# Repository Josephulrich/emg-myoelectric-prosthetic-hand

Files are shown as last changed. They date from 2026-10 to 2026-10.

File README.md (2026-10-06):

<div align="center">

# EMG Myoelectric Prosthetic Hand

### 3D-printed robotic hand driven by muscle signals, with haptic, visual and audio feedback







**From muscle contraction to finger motion: a final-year biomedical instrumentation project at Sup Galilée, Sorbonne Paris Nord (2026).**

</div>

| Assembled prototype | On the test bench | Hands-on demo |
|---|---|---|
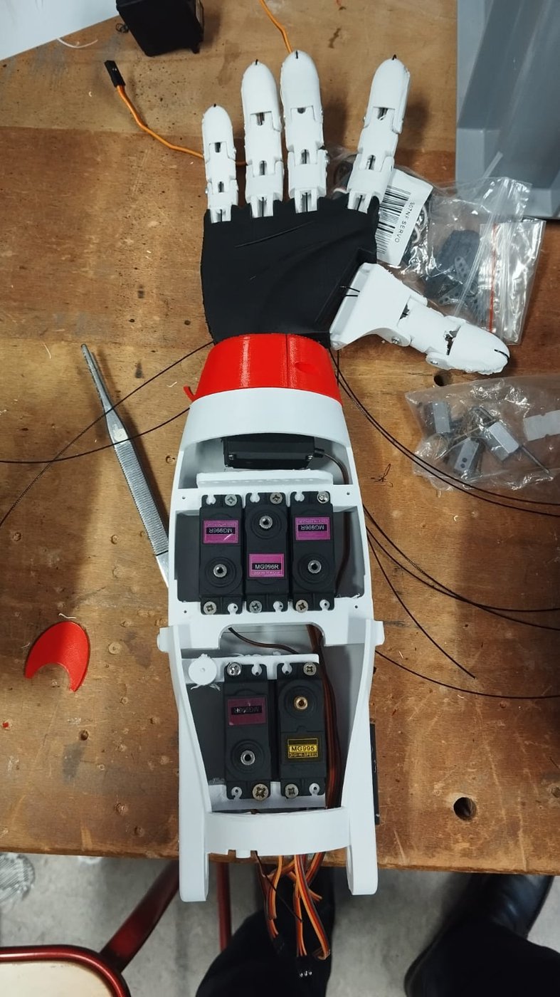
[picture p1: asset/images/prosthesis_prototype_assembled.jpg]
Prototype
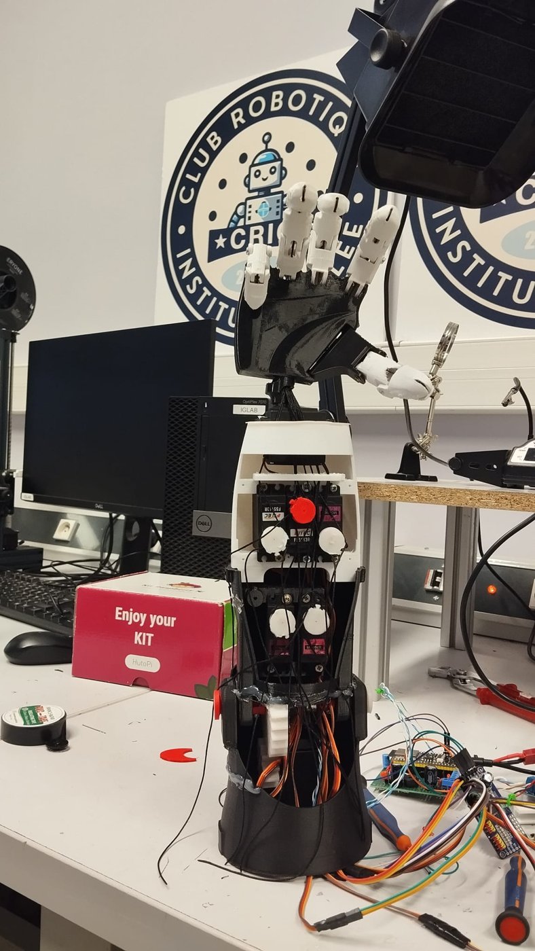
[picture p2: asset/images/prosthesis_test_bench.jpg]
Test bench
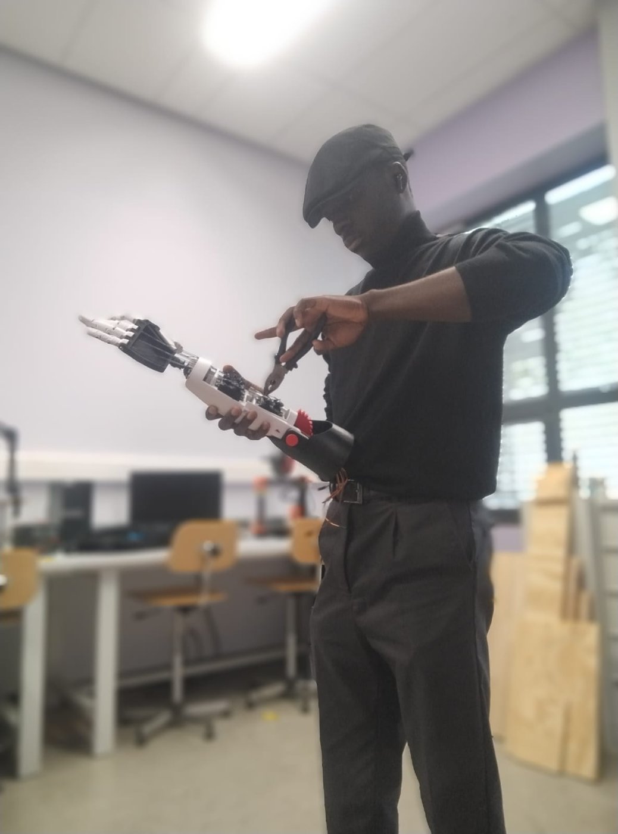
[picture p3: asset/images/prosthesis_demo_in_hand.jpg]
Demo
|  |  |  |

## The question

> **How do you turn biological muscle activity into controlled mechanical motion?**

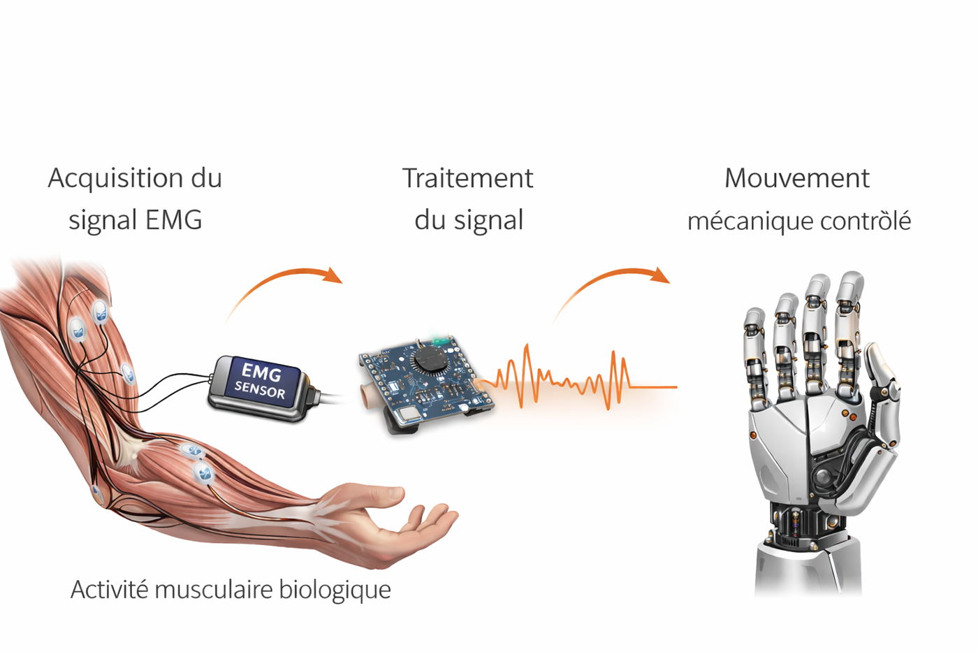
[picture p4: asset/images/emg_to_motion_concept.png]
EMG to motion concept


Myoelectric prostheses use the electrical activity of residual muscles to drive actuators. This project builds a complete, working chain around that idea:

- reliable **EMG acquisition** from the forearm,
- signal conditioning and **decision logic** on an embedded MCU,
- control of a **multi-finger 3D-printed hand**,
- **sensory feedback** to the user (vibration, light, sound),
- a **physical prototype** fabricated and tested.

| Parameter | Value |
|---|---|
| EMG sensor | MyoWare module (differential amplifier + analog filtering) |
| Main controller | ESP32-S3 |
| Actuator driver | PCA9685, 16-channel PWM over I2C |
| Actuators | Servomotors with nylon-tendon transmission |
| Auxiliary sensors | FSR RP-S40-ST (pressure), BMP280 (environment), potentiometer |
| Feedback | Vibration motor, passive buzzer, WS2812B LED strip |
| Power | Two separate rails: ~5 V logic, ~5.5 V actuators |
| Structure | PLA + TPU 3D printing, 1 mm nylon tendons |
| Total mass | ~470 g |

## System architecture

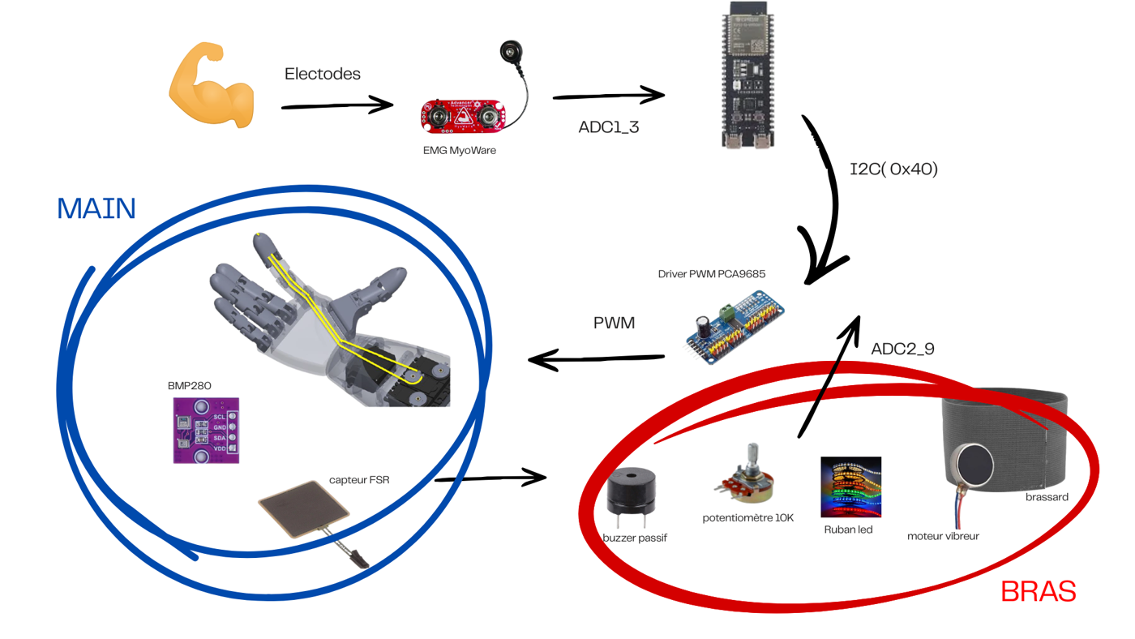
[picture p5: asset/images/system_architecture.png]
System architecture


```text
 Forearm muscle
      │ µV to mV
      ▼
 ┌───────────────┐  analog   ┌──────────────────────┐   I2C   ┌──────────┐  PWM  ┌─────────────┐
 │ MyoWare EMG   │ ────────► │      ESP32-S3        │ ──────► │ PCA9685  │ ────► │ Finger      │
 │ amp + filter  │   ADC     │ acquisition, logic,  │         │ 16-ch PWM│       │ servos      │
 └───────────────┘           │ feedback control     │         └──────────┘       └──────┬──────┘
                             └──────────┬───────────┘                                   │ tendons
     FSR RP-S40-ST ── ADC ─────────────►│                                               ▼
     BMP280 ────────── I2C ────────────►│                                       3D-printed hand
     Potentiometer ─── ADC ────────────►│
                                        ├──► Vibration motor (haptic)
                                        ├──► Buzzer (audio)
                                        └──► WS2812B LED strip (visual)

  Logic rail ~5 V  ║  Actuator rail ~5.5 V   (separated to keep motor noise out of the EMG chain)
```

## EMG acquisition

The EMG signal is tiny (µV to a few mV) with a useful band of roughly **20 to 450 Hz**. The MyoWare module provides differential amplification, analog filtering and an analog output read by the ESP32-S3 ADC.

A typical EMG chain:

```text
Electrodes ──► Differential amplification ──► High-pass (drift) ──► Low-pass (HF noise) ──► 50 Hz rejection ──► Envelope ──► ADC
```

Electrode placement proved to be one of the main factors of signal quality.

| Relaxed forearm | Contraction |
|---|---|
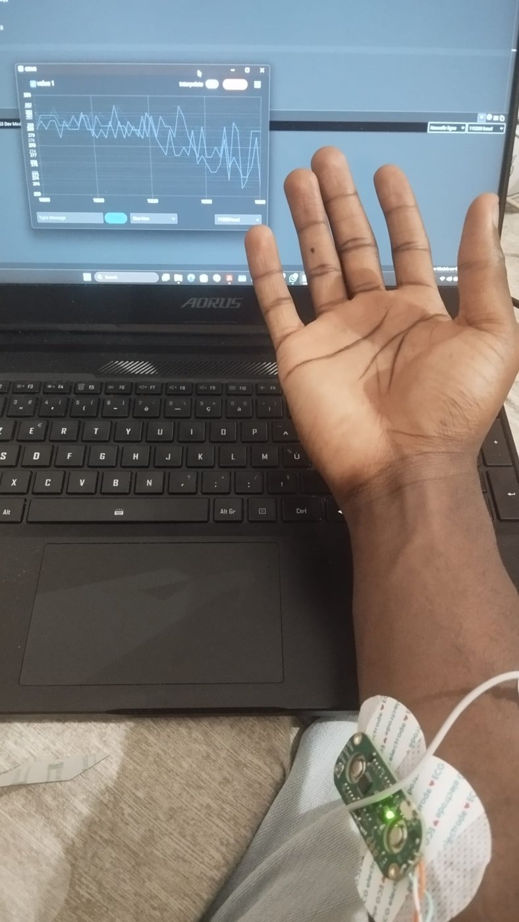
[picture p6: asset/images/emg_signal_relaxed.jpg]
Relaxed
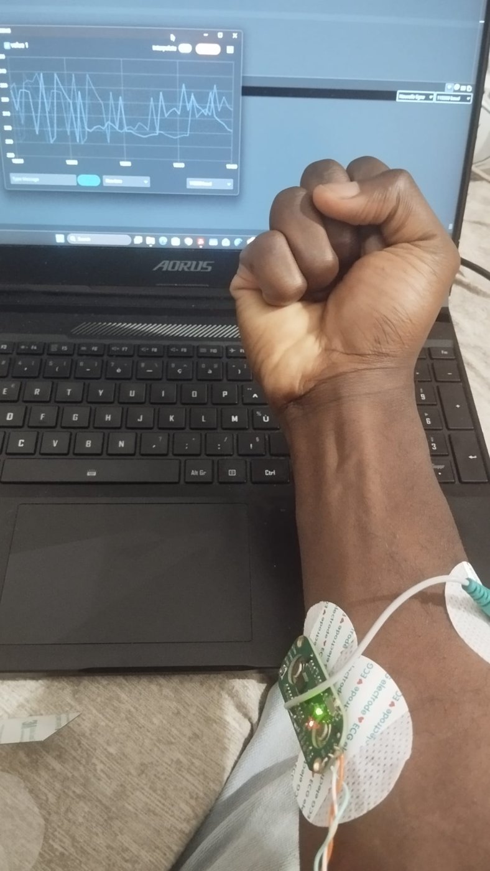
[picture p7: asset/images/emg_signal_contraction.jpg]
Contraction
|  |  |

<details>
<summary><b>Electrode placement and FSR serial readings</b></summary>

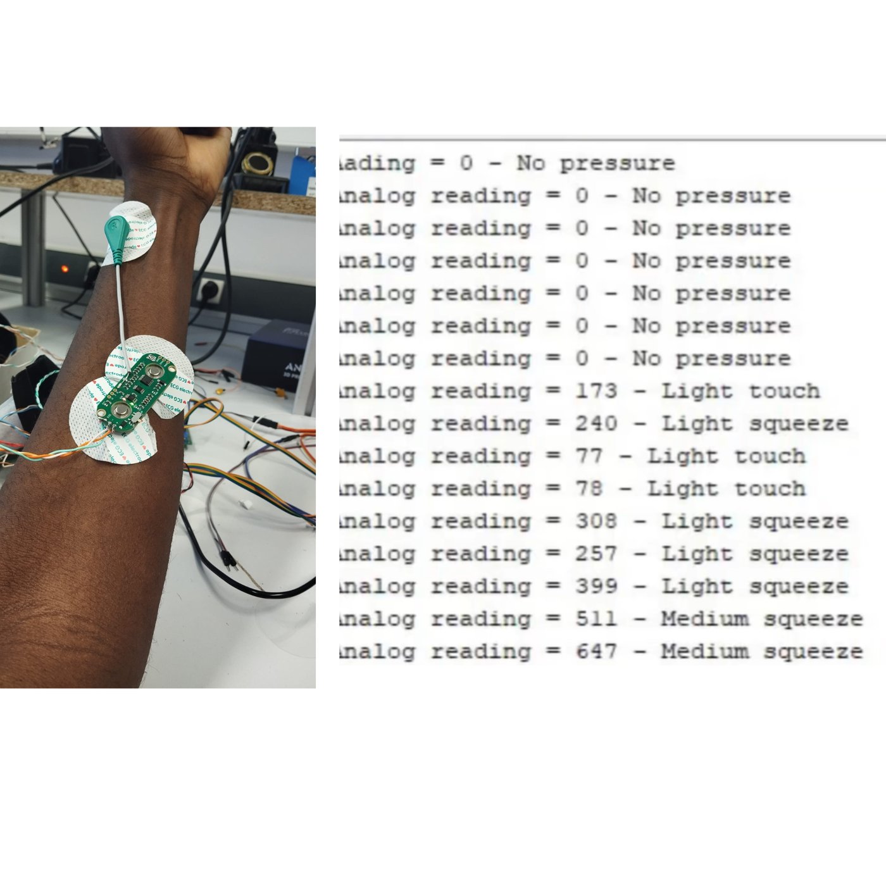
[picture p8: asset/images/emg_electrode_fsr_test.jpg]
Electrode and FSR test


</details>

## Electronics

| Prototype board | Integration in the forearm | Power rail check |
|---|---|---|
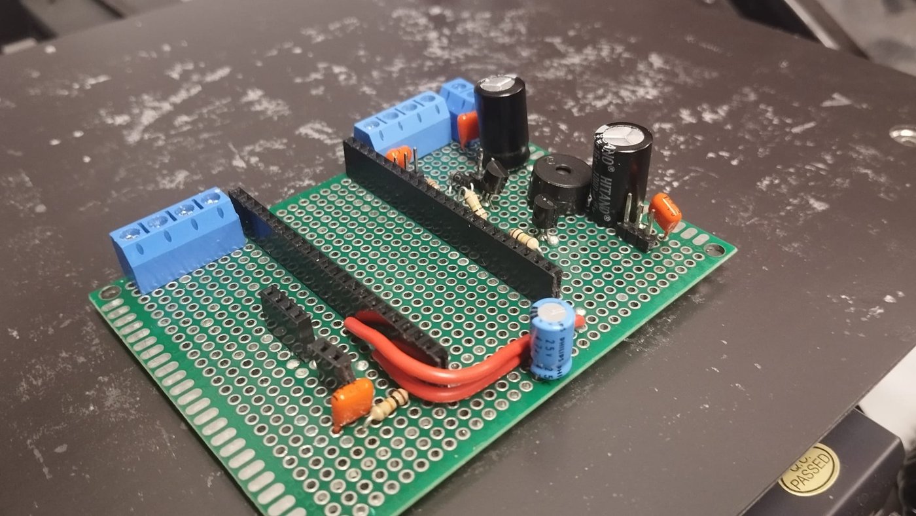
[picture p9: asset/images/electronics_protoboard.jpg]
Protoboard
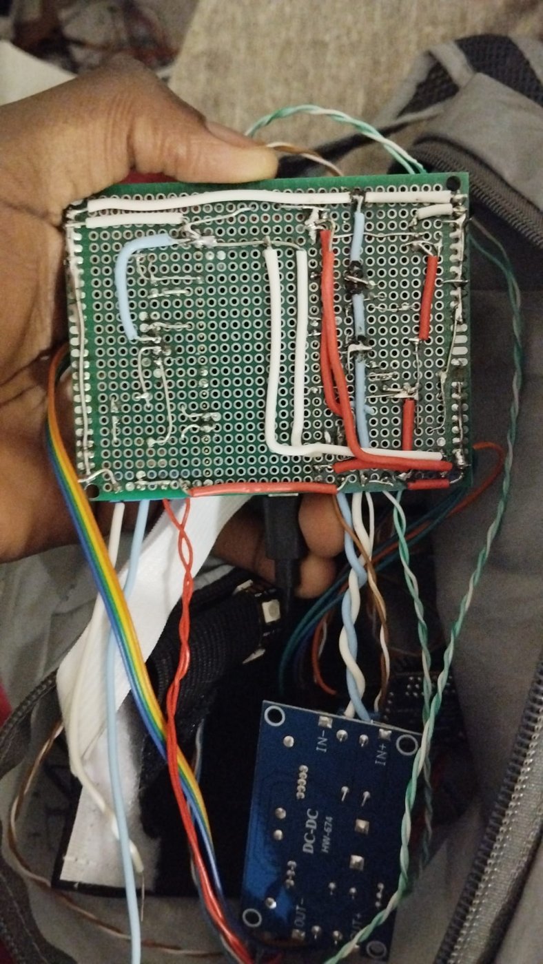
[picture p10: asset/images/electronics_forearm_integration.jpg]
Forearm integration
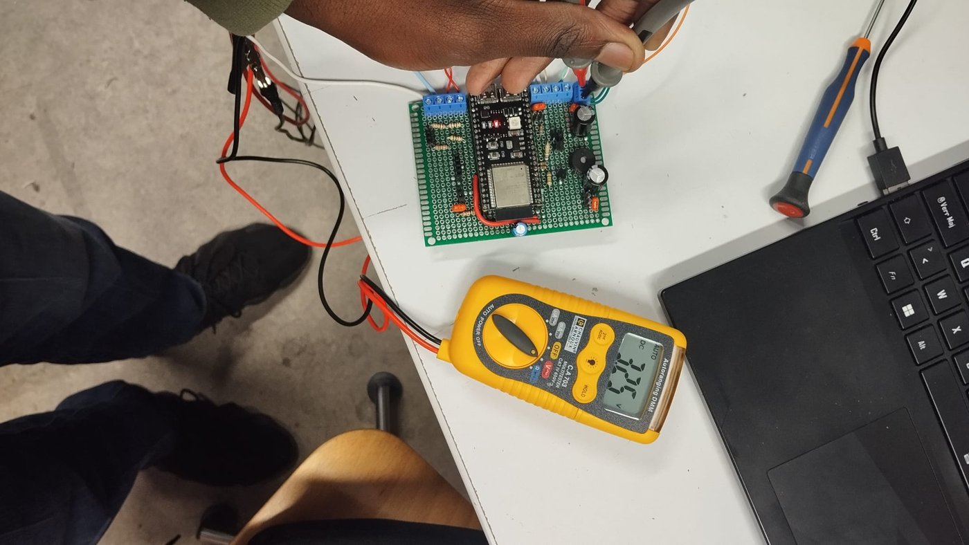
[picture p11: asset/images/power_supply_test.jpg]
Power test
|  |  |  |

### Actuation

The ESP32-S3 drives the servos through a **PCA9685** over I2C: 16 independent, stable PWM channels, simultaneous multi-finger control and less load on the MCU.

### Pressure sensing

The **RP-S40-ST** FSR (40 x 40 mm, 36 x 36 mm active area, ~0.45 mm thick, ~20 g to 10 kg range, response under 10 ms according to its datasheet) is read through a voltage divider. Its resistance drops as force increases. It is used to detect contact, estimate grip qualitatively and trigger feedback above a threshold. It is a relative pressure sensor, not a precision load cell: non-linear response and hysteresis.

### Power

Two separate rails prevent servo current peaks from injecting noise into the EMG acquisition: about **5 V for logic** and about **5.5 V for actuators**.

<p align="center">
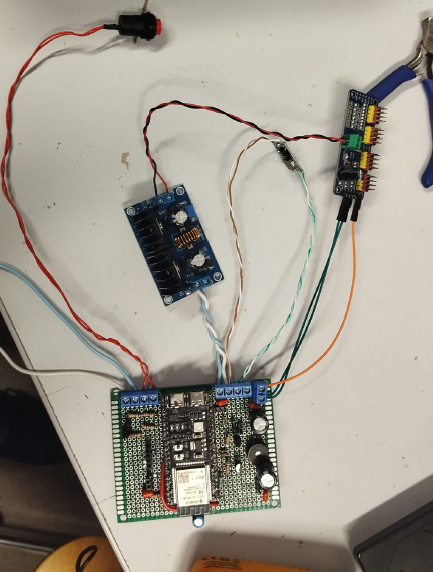
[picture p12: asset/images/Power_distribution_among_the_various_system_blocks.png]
Power distribution among the system blocks
  
</p>
<p align="center"><i>Power distribution wiring: DC/DC converter, main control board and actuator rail.</i></p>

## Mechanical design

| Hand CAD | Forearm integration CAD |
|---|---|
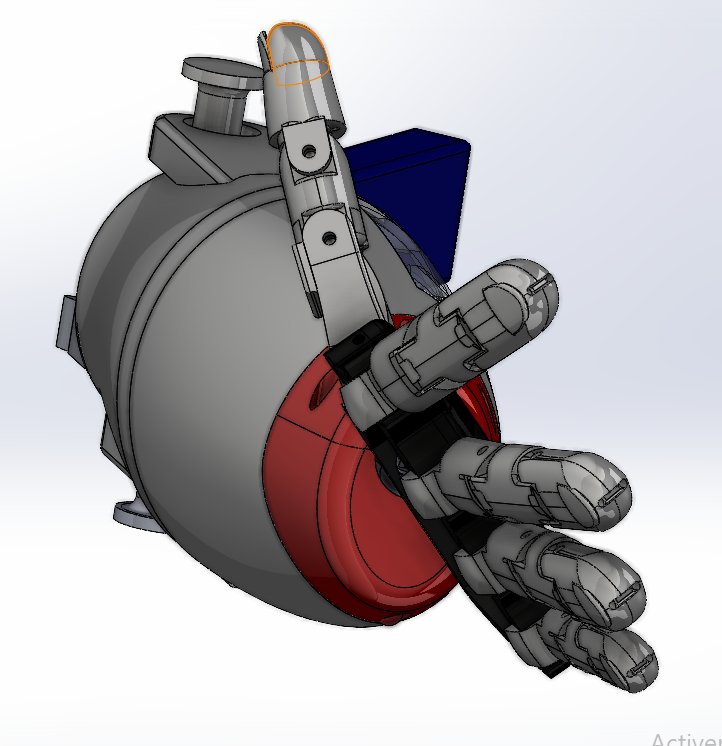
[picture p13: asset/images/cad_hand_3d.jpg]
CAD hand
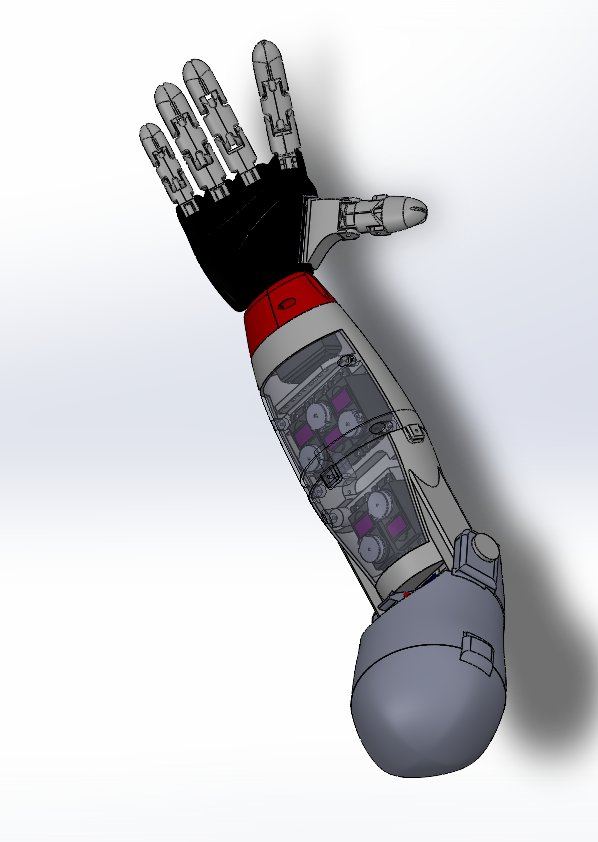
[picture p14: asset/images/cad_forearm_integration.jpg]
CAD forearm
|  |  |

The CAD defines the overall geometry, the space for boards, sensors and servos, and the routing of the tendon transmissions.

> **Credit.** The mechanical design is partially based on an existing model that was acquired and then modified for this project. Electronics integration, firmware, experiments and documentation are my own work.

## Fabrication

| 3D printing | Mechanical assembly |
|---|---|
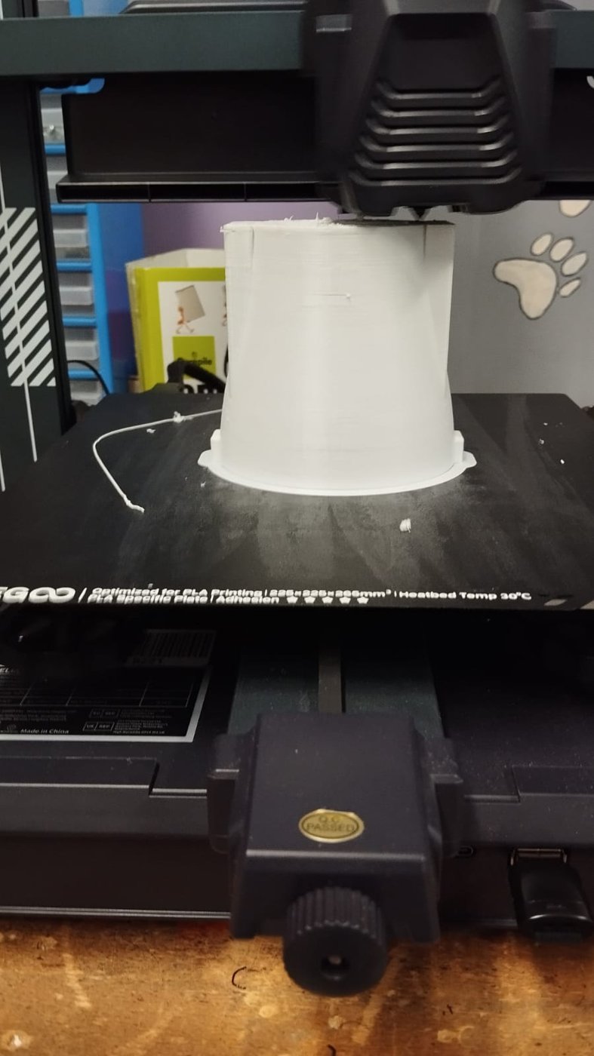
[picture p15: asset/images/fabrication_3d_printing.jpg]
3D printing
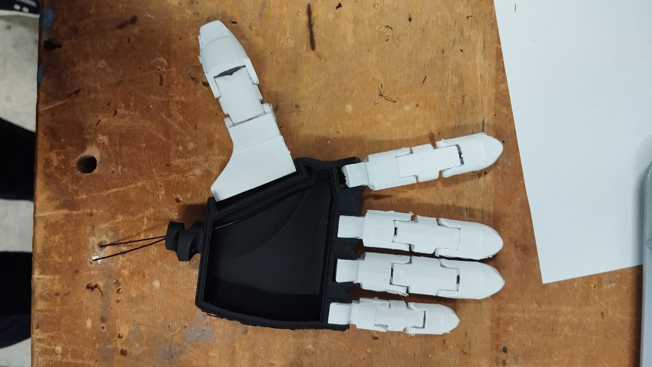
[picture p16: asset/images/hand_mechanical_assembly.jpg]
Hand assembly
|  |  |

- PLA 1.75 mm for the rigid structure
- TPU 1.75 mm for flexible parts
- 1 mm nylon line for tendon transmissions

## Sensory feedback

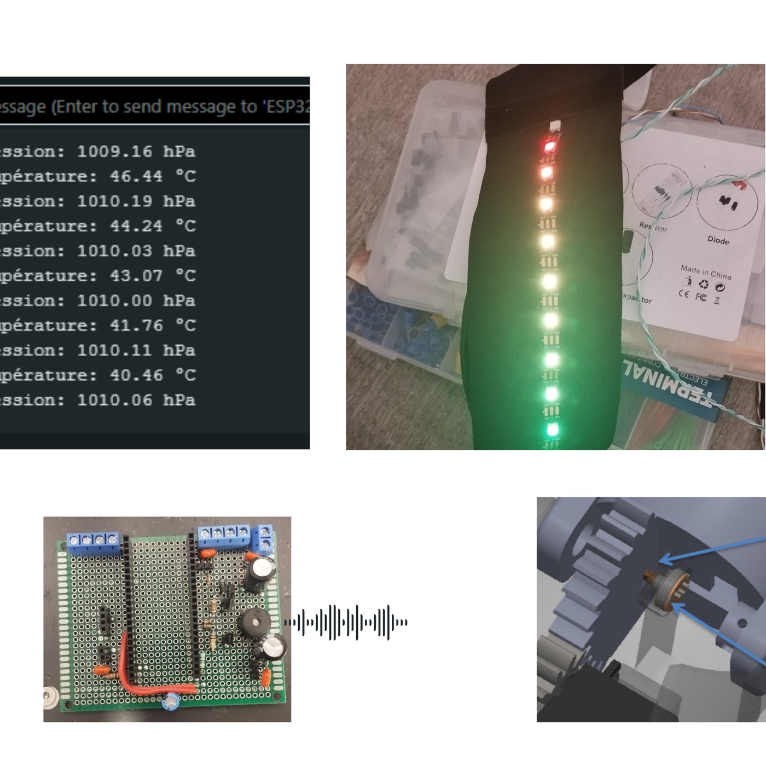
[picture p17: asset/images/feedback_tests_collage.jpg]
Feedback tests


| Modality | Device | Use |
|---|---|---|
| Haptic | Vibration motor | Signals contact or grip events to the user |
| Visual | WS2812B LED strip | System state and intensity |
| Audio | Passive buzzer | Alerts and confirmations |

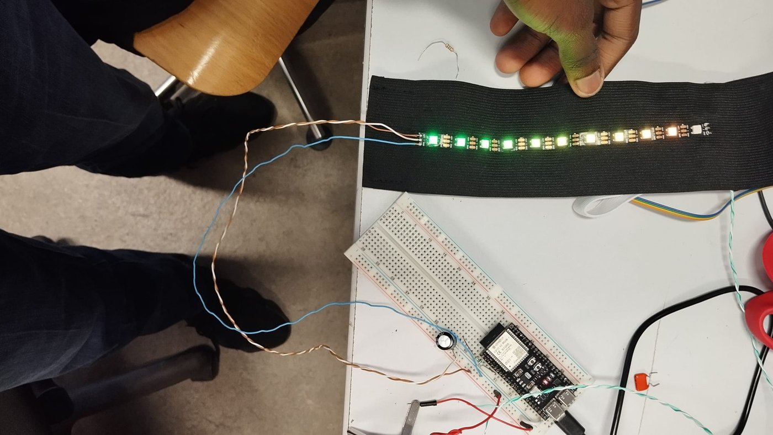
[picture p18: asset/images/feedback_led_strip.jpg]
LED feedback on forearm


## Firmware

Each subsystem was developed and validated in its own Arduino sketch before integration:

| Sketch | Purpose |
|---|---|
| [`firmware/`](firmware/firmware.ino) | Integrated firmware: EMG acquisition, decision logic, actuator and feedback control |
| [`test_emg/`](test_emg/test_emg.ino) | EMG signal acquisition test |
| [`test_servo/`](test_servo/test_servo.ino) | Servo motion test |
| [`test_servo_continus/`](test_servo_continus/test_servo_continus.ino) | Continuous-rotation servo test |
| [`pos_zero/`](pos_zero/pos_zero.ino) | Servo zero-position calibration |
| [`pos_standard/`](pos_standard/pos_standard.ino) | Standard hand position |
| [`FSR/`](FSR/FSR.ino) | FSR pressure sensor reading |
| [`test_bmp280/`](test_bmp280/test_bmp280.ino) | BMP280 sensor test |
| [`moteur_vibreur/`](moteur_vibreur/moteur_vibreur.ino) | Vibration motor (haptic feedback) |
| [`buzzer/`](buzzer/buzzer.ino) | Buzzer test |
| [`volume_buzzer/`](volume_buzzer/volume_buzzer.ino) | Buzzer volume control |
| [`ruban_led/`](ruban_led/ruban_led.ino) | WS2812B LED strip test |
| [`gradient_rgb/`](gradient_rgb/gradient_rgb.ino) | RGB gradient effect for visual feedback |

Control principle: the EMG level is sampled by the ADC, compared against thresholds or states, then translated into servo commands through the PCA9685 while the other outputs drive the feedback devices.

## Results

Validated on the physical prototype:

- [x] EMG acquisition on a real forearm, with clear difference between rest and contraction
- [x] Command chain from EMG to servo motion
- [x] Mechanical integration of electronics in the forearm
- [x] Haptic, visual and audio feedback modules working

Measured performance (latency, grip force, repeatability over cycles) is still to be characterised.

## Limitations

- EMG remains sensitive to noise and to **electrode placement**.
- Single-channel, threshold-based control: no proportional or multi-gesture control yet.
- Electronics still on a **prototyping board**, bulky.
- Bench prototype only, not a medical device. During tests, mains-powered equipment connected to a person requires isolation per **IEC 60601-1**, which constrained the test setup.

## Future work

- [ ] Multi-channel EMG and **AI-based gesture classification** on the ESP32-S3
- [ ] Dedicated **PCB** to replace the protoboard
- [ ] Miniaturisation and battery power for full portability
- [ ] Stronger mechanics and proportional grip control using the FSR
- [ ] Long term: biomedical certification path and CE marking

## Repository structure

```text
.
├── asset/images/          # README visuals
├── firmware/              # Integrated firmware
├── test_emg/  test_servo/  test_servo_continus/
├── pos_zero/  pos_standard/
├── FSR/  test_bmp280/
├── moteur_vibreur/  buzzer/  volume_buzzer/
├── ruban_led/  gradient_rgb/
├── .gitignore
└── README.md
```

## Acknowledgements

Supervisors Nadia Djaker and Jean-Marie Feybesse, Violeta Rodriguez for biology and anatomy guidance, Maxime Divet (REEV CARE) for technical exchanges, and the CRIG robotics club for daily support.

## Skills

Biomedical instrumentation · EMG signal acquisition · Embedded systems (ESP32-S3) · I2C / PWM actuation · Sensor integration · Haptic feedback · 3D CAD and additive manufacturing · Prototyping and testing

## Author

**Joseph Mbode**

Embedded systems and biomedical engineering, Sup Galilée, Sorbonne Paris Nord.

- LinkedIn: [Joseph Mbode](https://www.linkedin.com/in/joseph-mbode)
- GitHub: [@Josephulrich](https://github.com/Josephulrich)

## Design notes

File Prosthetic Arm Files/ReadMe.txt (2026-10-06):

DESCRIPTION
###########

Model of a 3D printed prototype bionic/prosthetic arm, 2014.

Modelled by an undegraduate Mechatronics Engineering student as part of a final year thesis.

Models are not at a professional standard.

This model is intended purely for educational use around mechanical design and 3D modelling.

Good Luck!

FILES
#####

1. Open the assembly document 'Full Assembly Exploded'.

2. If the model is in an exploded state, to return it to normal go to 'ConfigurationManager' on 
   the left hand side of the screen near the Design History Tree.

3. Expand 'Default' view by clicking the down arrow button and right click 'ExplView1' and select 'collapse', or vice versa if you wish to explode it

4. Discuss in the comments and issues/ideas and feel free to build apon this design and further share for educational purposes.

Credit 'Mahdi Designs' YouTube 
      ######################

Creative Commons License
https://creativecommons.org/licenses/by-nc-sa/3.0/

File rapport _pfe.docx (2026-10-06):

PROJET DE FIN D’ETUDE :

PROTHÈSE MYOÉLECTRIQUE

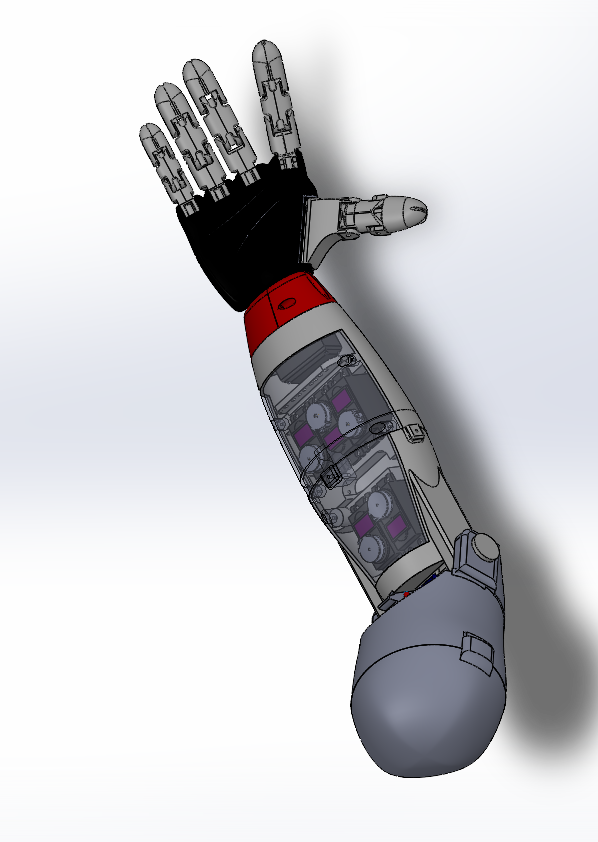
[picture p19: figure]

Redigé par : Joseph Ulrich MBODE NGOMBE

Encadré par : J. -M. FEYBESSE

N. DJAKER

Année : 2025/2026

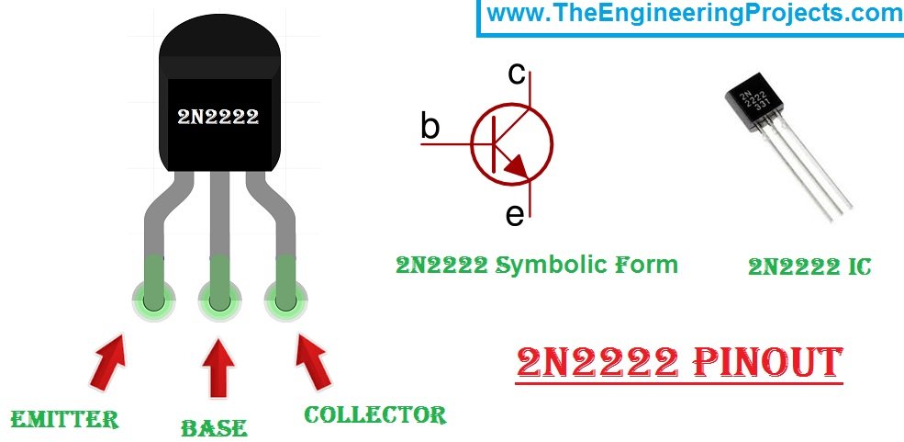
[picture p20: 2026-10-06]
2N2222-Pinout.jpg

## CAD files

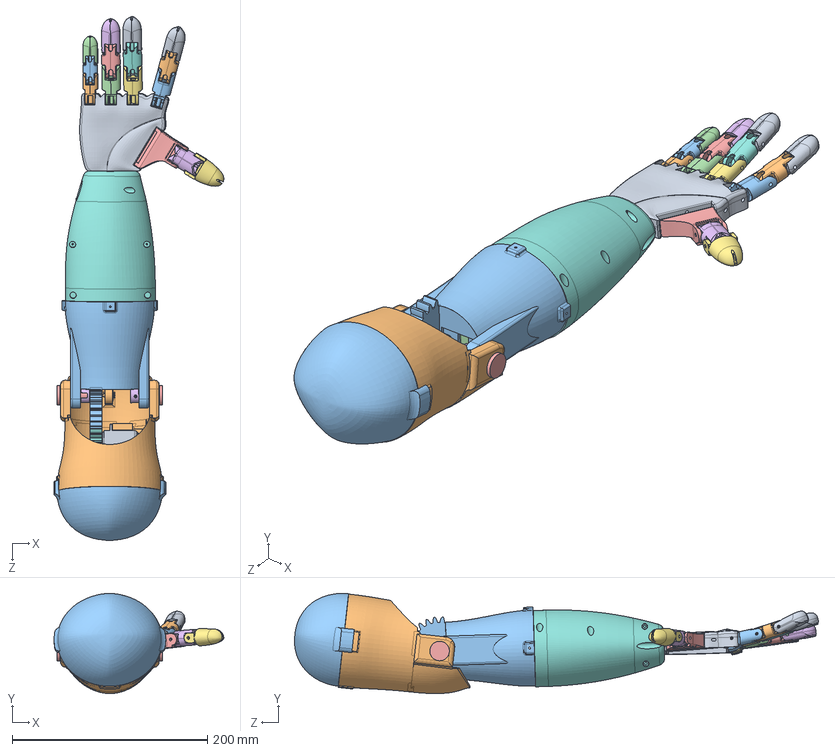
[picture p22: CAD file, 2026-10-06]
Prosthetic Arm Files/Prosthetic Arm CAD Model/Full Assembly Exploded.SLDASM
173.8 x 102.5 x 536.5 mm
Index Finger Tip
Index Finger Middle
Index Finger Bottom Plus Cutout
Ring Finger Bottom Plus Cutout
Ring Finger Middle
Ring Finger Tip
Middle Finger Bottom Plus Cutout
Middle Finger Middle
Middle Finger Tip
Pinky Finger Bottom Plus Cutout
Pinky Finger Middle
Pinky Finger Tip
Thumb Lower
Thumb Middle
Thumb tip 2
Forearm
Standard Servo x 6
Bicep
Upper Forearm with Gear
Battery
Locking Pins x 2
Pin Lock x 2
Horn x 3
spur gear_iso
Palm _ Optimised Connector
TowerPro mg996r potentiometer
Upper Bicep Cap

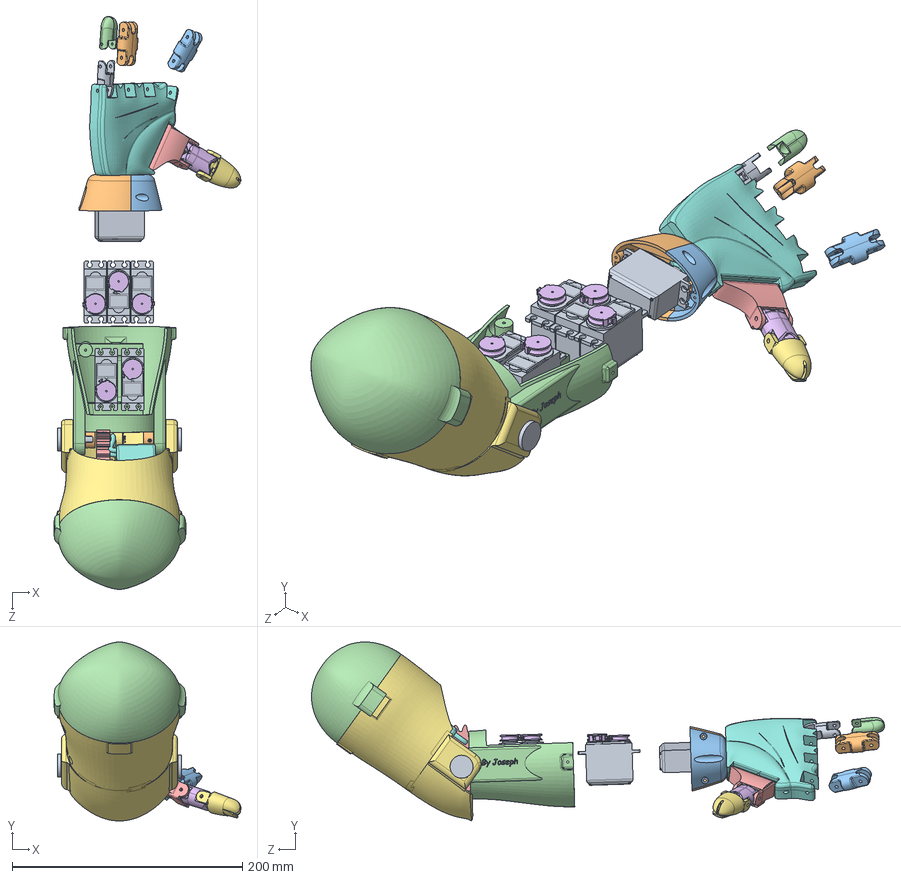
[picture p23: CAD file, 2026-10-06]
Prosthetic Arm Files/Prosthetic Arm Updated CAD Model - SolidWorks 2019/Full Assembly.SLDASM
162.2 x 155.5 x 497.7 mm
Index Finger Middle
Ring Finger Middle
Pinky Finger Bottom Plus Cutout
Pinky Finger Tip
Thumb Lower
Thumb Middle
Thumb tip 2
Palm & Optimised Connector
Standard Servo x 7
Wrist Forearm Section A
Wrist Forearm Section B
Upper Forearm Large
Forearm Gear Split
Horn x 5
Battery
Locking Pins x 2
Pin Lock x 2
spur gear_iso
TowerPro mg996r potentiometer

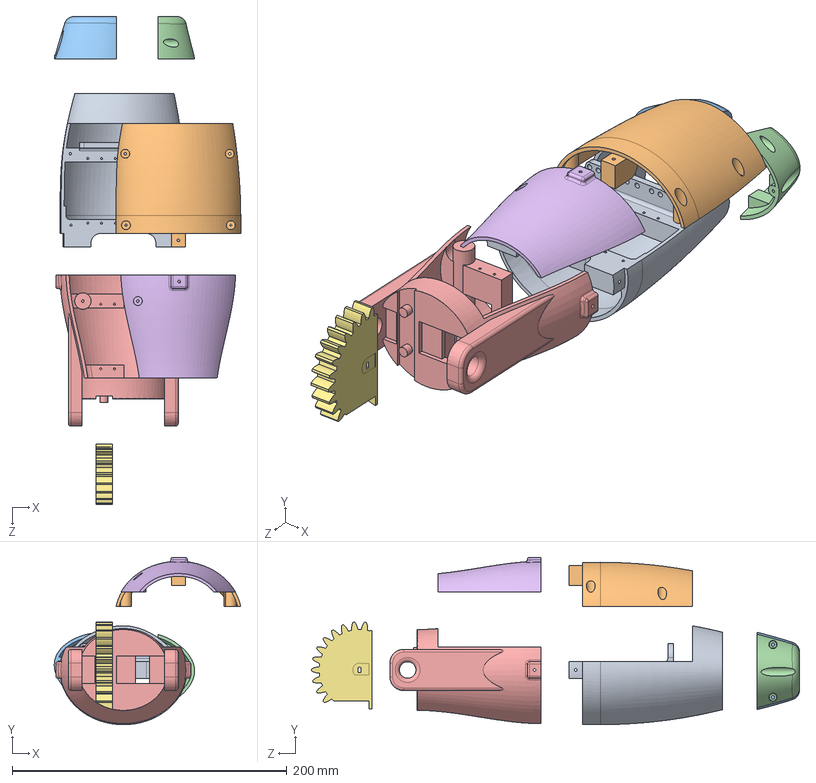
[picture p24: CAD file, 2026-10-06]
Prosthetic Arm Files/Prosthetic Arm Updated CAD Model - SolidWorks 2019/Forearm Assembly.SLDASM
135.7 x 121.8 x 355.0 mm
Mid Forearm Large
Mid Forearm Small
Wrist Forearm Section A
Wrist Forearm Section B
Upper Forearm Large
Upper Forearm Small
Forearm Gear Split

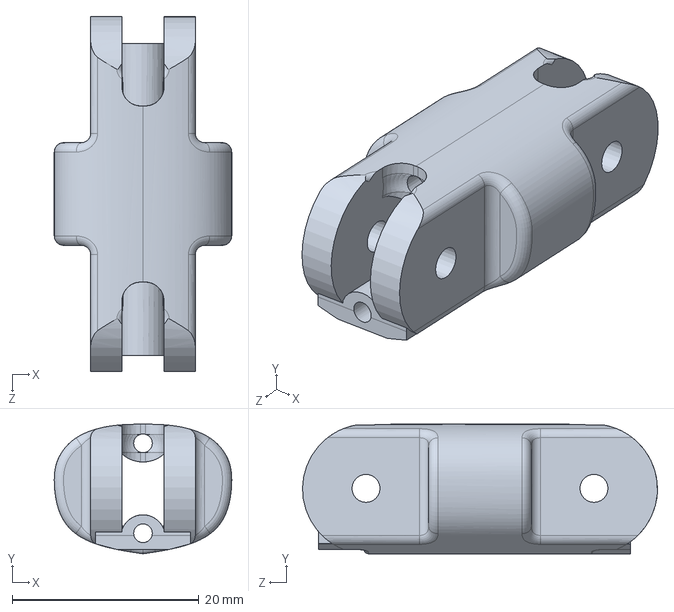
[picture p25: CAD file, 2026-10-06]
Prosthetic Arm Files/Prosthetic Arm CAD Model/Ring Finger Middle.SLDPRT
19.0 x 13.9 x 38.0 mm

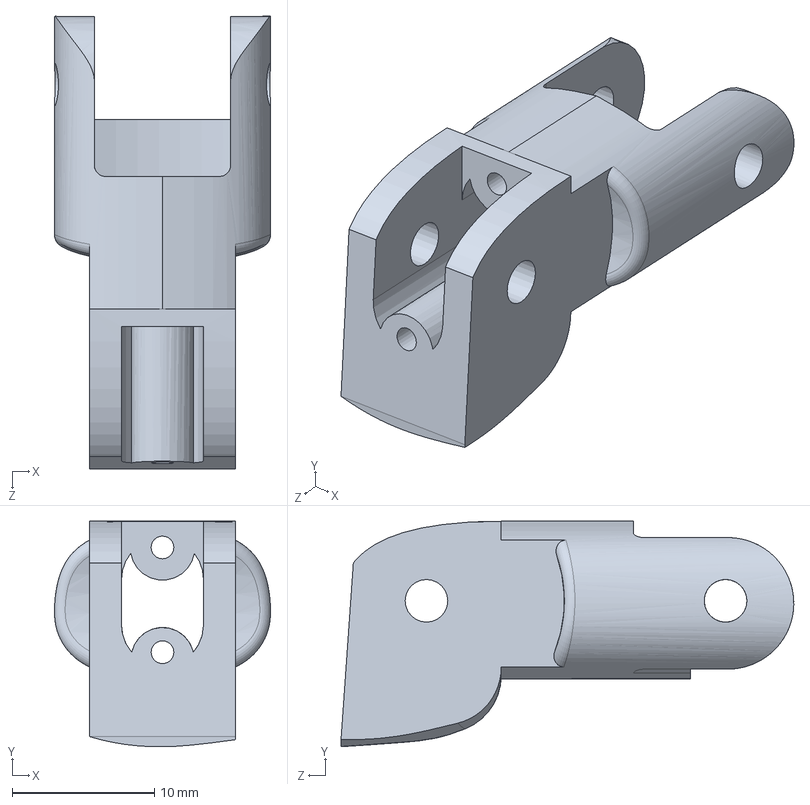
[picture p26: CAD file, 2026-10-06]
Prosthetic Arm Files/Prosthetic Arm Updated CAD Model - SolidWorks 2019/Pinky Finger Bottom Plus Cutout.SLDPRT
15.2 x 15.9 x 31.9 mm

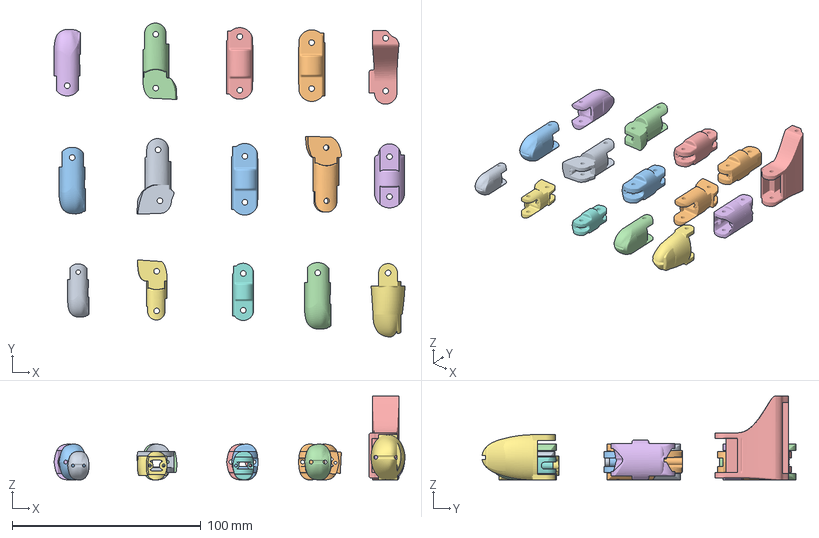
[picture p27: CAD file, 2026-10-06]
Prosthetic Arm Files/STL Files for 3D Printed Arm/EN4_Index Finger Bottom Plus Cutout.3mf
186.2 x 166.5 x 44.5 mm
Index Finger Bottom Plus Cutout.STL
Index Finger Middle.STL
Index Finger Tip.STL
Middle Finger Bottom Plus Cutout.STL
Middle Finger Middle.STL
Middle Finger Tip.STL
Pinky Finger Bottom Plus Cutout.STL
Pinky Finger Middle.STL
Pinky Finger Tip.STL
Ring Finger Bottom Plus Cutout.STL
Ring Finger Middle.STL
Ring Finger Tip.STL
Thumb Lower.STL
Thumb Middle.STL
Thumb tip 2.STL

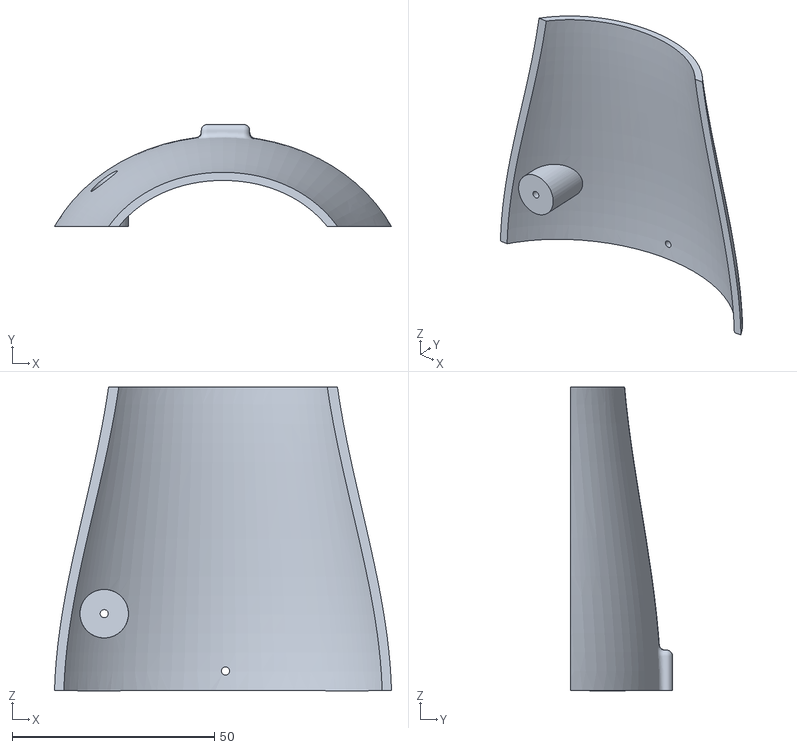
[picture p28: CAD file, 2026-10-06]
Prosthetic Arm Files/STL Files for 3D Printed Arm/Printable Files 4.0/Already printed/Upper Forearm Small.STL
83.4 x 25.3 x 75.1

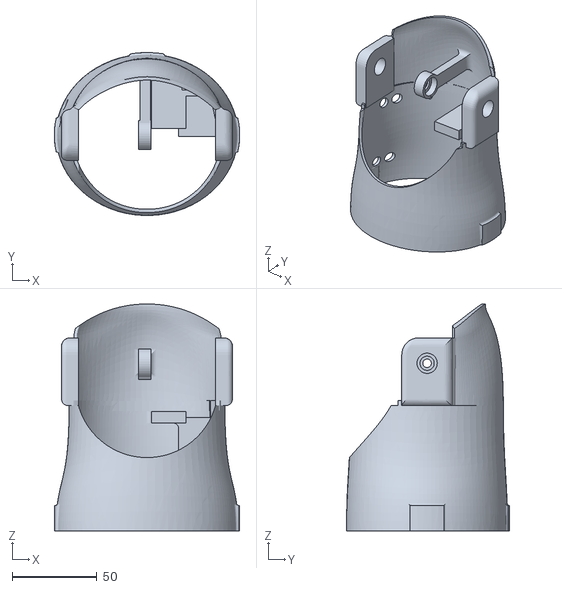
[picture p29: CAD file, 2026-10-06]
Prosthetic Arm Files/STL Files for 3D Printed Arm/Printable Files 4.0/Bicep/Bicep.STL
109.5 x 96.2 x 134.0

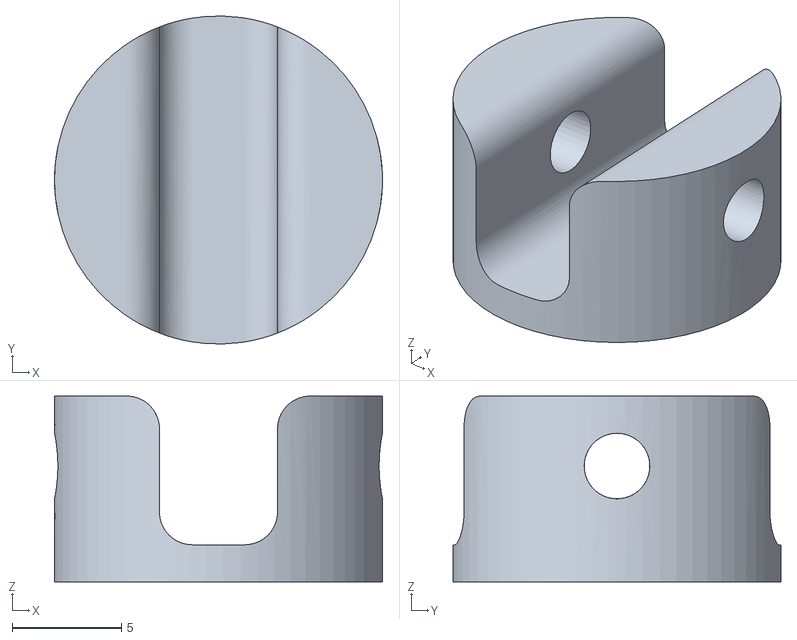
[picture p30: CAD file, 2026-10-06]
Prosthetic Arm Files/STL Files for 3D Printed Arm/Printable Files 4.0/Elbow/Pin Lock.STL
15.0 x 15.0 x 8.50

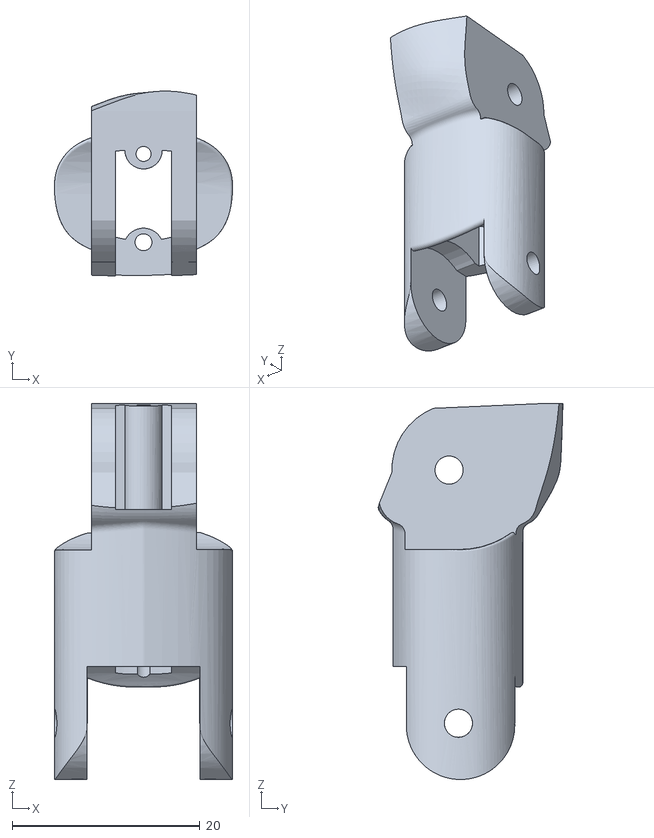
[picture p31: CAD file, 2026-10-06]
Prosthetic Arm Files/STL Files for 3D Printed Arm/Printable Files 4.0/Fingers/Index/Index Finger Bottom Plus Cutout.STL
19.0 x 19.7 x 40.1

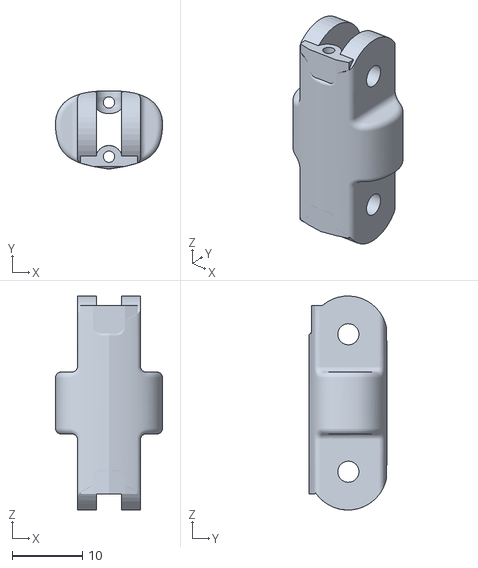
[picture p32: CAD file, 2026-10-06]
Prosthetic Arm Files/STL Files for 3D Printed Arm/Printable Files 4.0/Fingers/Pinky/Pinky Finger Middle.STL
15.2 x 11.1 x 30.4

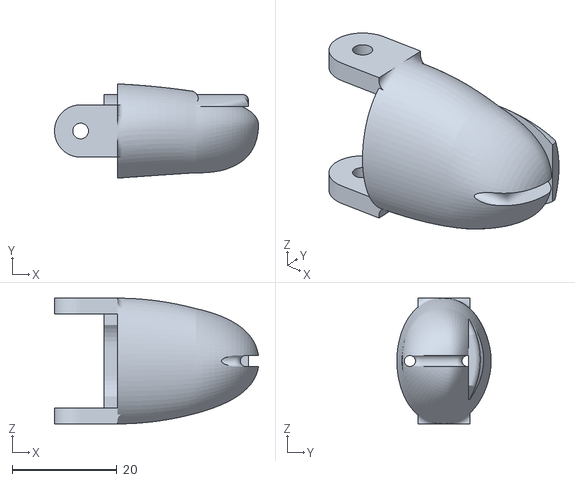
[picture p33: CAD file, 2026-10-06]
Prosthetic Arm Files/STL Files for 3D Printed Arm/Printable Files 4.0/Fingers/Thumb/Thumb tip 2.STL
38.9 x 18.0 x 24.0

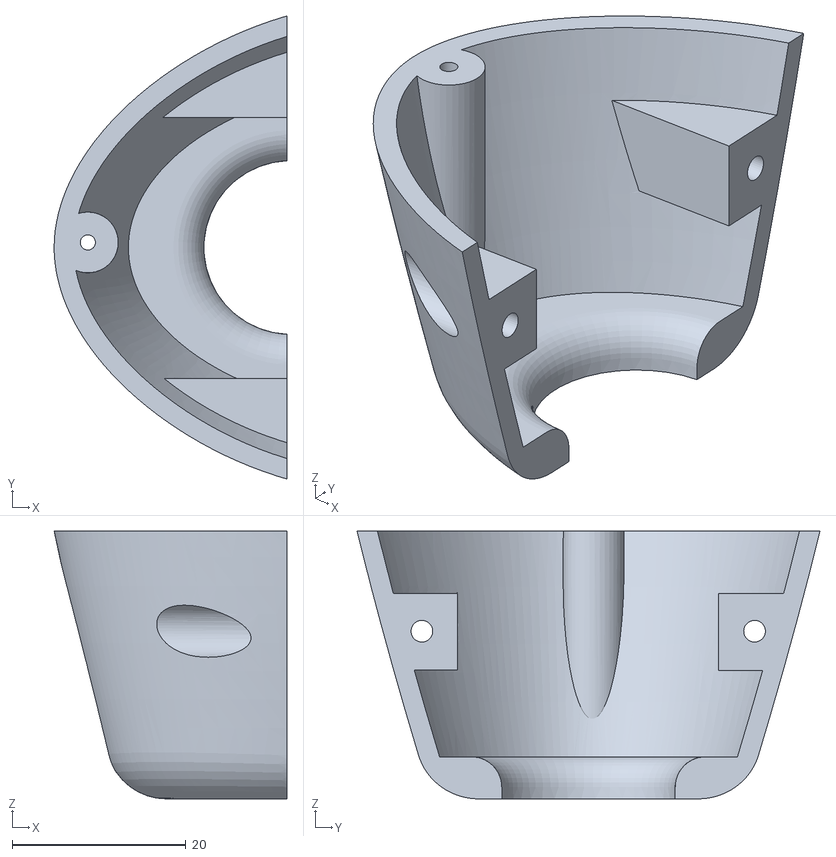
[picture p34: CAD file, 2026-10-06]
Prosthetic Arm Files/STL Files for 3D Printed Arm/Printable Files 4.0/Forearm/Wrist Forearm Section B.STL
26.8 x 53.3 x 30.9

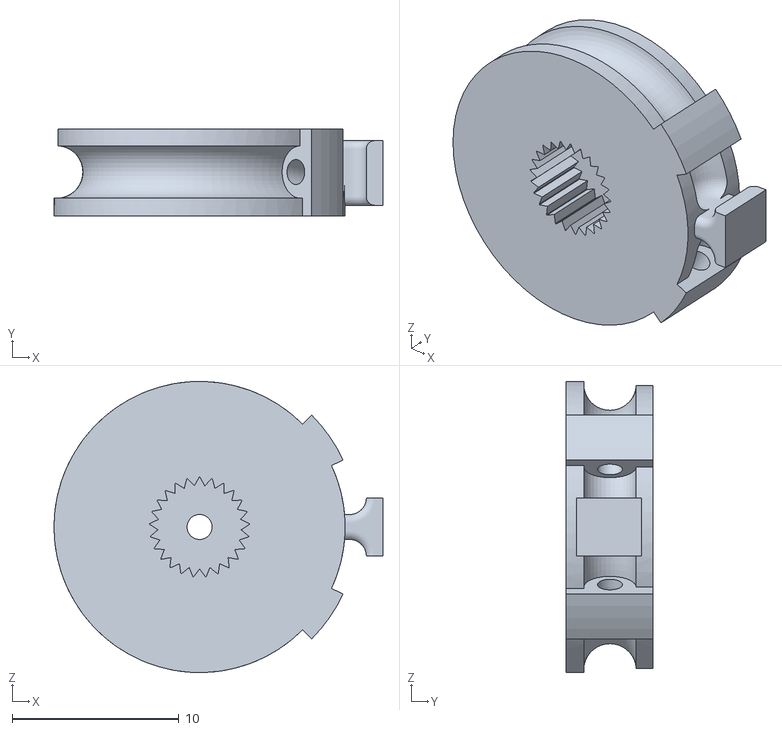
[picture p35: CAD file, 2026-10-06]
Prosthetic Arm Files/STL Files for 3D Printed Arm/Printable Files 4.0/Horn.STL
19.7 x 5.20 x 17.5

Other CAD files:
Prosthetic Arm Files/STL Files for 3D Printed Arm/Printable Files 4.0/Fingers/Middle/Middle Finger Middle.STL
Prosthetic Arm Files/STL Files for 3D Printed Arm/Printable Files 4.0/Fingers/Ring/Ring Finger Middle.STL
Prosthetic Arm Files/STL Files for 3D Printed Arm/Printable Files 4.0/Palm/Palm Finger Cutouts Back.STL
Prosthetic Arm Files/STL Files for 3D Printed Arm/Printable Files 4.0/Upper Forearm/Upper Forearm Small.STL
Prosthetic Arm Files/Prosthetic Arm CAD Model/Battery.SLDPRT
Prosthetic Arm Files/Prosthetic Arm CAD Model/Bicep.SLDPRT
Prosthetic Arm Files/Prosthetic Arm CAD Model/Forearm.SLDPRT
Prosthetic Arm Files/Prosthetic Arm CAD Model/Horn.SLDPRT
Prosthetic Arm Files/Prosthetic Arm CAD Model/Index Finger Bottom Plus Cutout.SLDPRT
Prosthetic Arm Files/Prosthetic Arm CAD Model/Index Finger Middle.SLDPRT
Prosthetic Arm Files/Prosthetic Arm CAD Model/Index Finger Tip.SLDPRT
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

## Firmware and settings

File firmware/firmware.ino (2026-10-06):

#include <Wire.h>
#include <Adafruit_PWMServoDriver.h>
#include <Adafruit_NeoPixel.h>
#include <Adafruit_BMP280.h>

#define sda 47
#define scl 48
#define BUZZ_PIN 15
#define vibro 16
#define sig_emg 46
#define FSR 1 
#define pot 20
#define LED_PIN 4




/*********ruuban led***************/
#define LED_PIN 4
#define LED_COUNT 10
#define led_type WS2812B
#define brightness 80

Adafruit_NeoPixel strip(LED_COUNT, LED_PIN, NEO_GRB + NEO_KHZ800);
/************************/

const float FSR_max = 10.0; //Kg
const float Temp_max = 40;//°C
const float vref = 3.3;
const float R0 = 10000.0;
const float gain_fsr = 1.0f;



/******BMP280 sensor Temp************/
Adafruit_BMP280 bmp;
/************************/


float adcToRes(int adc)//ADC---->RESISTANCE
{
  if (adc <= 0) return 1e9;                 
  float vout = (adc / 4095.0f) * vref;
  if (vout < 0.001f) vout = 0.001f;         
  float Rfsr = (vref * R0 / vout) - R0;
  return Rfsr;
}


float FRStoKG(float Rohm) //Resistance 
{
  float Rk = Rohm/1000;
  if(Rk<=0.0f)return 0.0f;

  //Etude scientifique
  float F_N = gain_fsr*271.0f*pow(Rk, -0.69f); //fprce approximatie en Newton

  float m_kg = F_N/9.81f;
  if(m_kg>10.0) m_kg = 10.0f; //limite normative du capteur 
  if(m_kg<0.0) m_kg  = 0.0f;

  return m_kg;
}

float fsrTokg_estimate(int adc)
{
  float R = adcToRes(adc);
  return FRStoKG(R);
}

//////////////////////////////////retour haptique//////////////////////////////////////

void updateFeedback(float level) {
  if (level < 0.0f) level = 0.0f;
  if (level > 1.0f) level = 1.0f;

  int ledsOn = (int)round(level * LED_COUNT);
  if (ledsOn > LED_COUNT) ledsOn = LED_COUNT;

  // dégradé vert -> rouge
  uint8_t r = (uint8_t)(255 * level);
  uint8_t g = (uint8_t)(255 * (1.0f - level));
  uint8_t b = 0;

  for (int i = 0; i < LED_COUNT; i++) {
    if (i < ledsOn) strip.setPixelColor(i, strip.Color(r, g, b));
    else            strip.setPixelColor(i, 0, 0, 0);
  }
  strip.show();


////vibro proportio
int duty = (int)(255*level);
ledcWrite(vibro, duty); 
}
//// température/buzzer
void checktemp()
{
  float t = bmp.readTemperature();

  if (t >= Temp_max)
  {
    ledcWrite(BUZZ_PIN, 128);   // ON (son)
  }
  else
  {
    ledcWrite(BUZZ_PIN, 0);     // OFF
  }
}

void checkcoude()
{
  int adc_val = analogRead(pot);
  Serial.print("POT(GPIO");
  Serial.print(pot);
  Serial.print(") = ");
  Serial.println(adc_val);
}

//////////////////////////////////////////////////////////////////////////////////
void setup() 
{
  Serial.begin(115200);
  analogReadResolution(12); //0 - 4095
  analogSetAttenuation(ADC_11db);  // important pour vref = 3.3v

  // Vibromoteurs PWM via 2N2222 sur GPIO16
// Vibromoteur PWM
      // Vibromoteur PWM
  ledcAttach(vibro, 2000, 8);
  ledcWrite(vibro, 0);      

  // Buzzer passif (PWM audio)
  ledcAttach(BUZZ_PIN, 2000, 8);   // 2 kHz
  ledcWrite(BUZZ_PIN, 0);           // OFF

  // Ruban LED  
  strip.begin();
  strip.show();
  strip.setBrightness(80);

  // I2C + BMP280
  Wire.begin(sda, scl);
  if (!bmp.begin(0x76)) {          // adresse BMP280 courante 
    Serial.println("BMP280 non trouve");
  }

  Serial.println("Init OK (FSR + LEDs + Vibro PWM + BMP)");
}

void loop()
{
  // ===== Lecture FSR =====
  int adc_fsr = analogRead(FSR);

  float Rfsr = adcToRes(adc_fsr);
  float force_kg = FRStoKG(Rfsr);

  float level = force_kg / FSR_max;
  updateFeedback(level);

  // ===== Lecture température =====
  float temperature = bmp.readTemperature();

  // ===== Affichage Moniteur Série =====
 Serial.printf(
  "FSR=%4d | Force=%5.2f kg | Temp=%5.2f C\n",
  adc_fsr,
  force_kg,
  temperature
);
  checktemp();
  checkcoude();
  delay(500); // rafraîchissement 2 Hz
}

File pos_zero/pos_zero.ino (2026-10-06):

#include <Wire.h>
#include <Adafruit_PWMServoDriver.h>

Adafruit_PWMServoDriver pwm = Adafruit_PWMServoDriver(0x40);

// Pour les servos ANGLE (0,3,4,6)
#define SERVOMIN_ANG 150   // à ajuster
#define SERVOMAX_ANG 600   // à ajuster

// Pour les servos CONTINUS (1,2,5) → neutre (STOP)
#define SERVOMIN_CONT 150  // même base
#define SERVOMAX_CONT 600
#define PULSE_STOP   ((SERVOMIN_CONT + SERVOMAX_CONT) / 2)  // ≈ 1,5 ms [web:70][web:72]

void setup() {
  Wire.begin(47, 48);      // SDA=47, SCL=48
  Serial.begin(115200);
  delay(1000);

  pwm.begin();
  pwm.setPWMFreq(50);      // 50 Hz pour servos [web:71]

  // 1) Servos positionnels → 0° sur 0,3,4,6
  setAngleServo(0, 0);
  setAngleServo(3, 0);
  setAngleServo(4, 0);
  setAngleServo(6, 0);

  // 2) Servos continus → STOP sur 1,2,5
  setContinuousStop(1);
  setContinuousStop(2);
  setContinuousStop(5);

  Serial.println("Reset terminé : angle=0° sur 0,3,4,6 et STOP sur 1,2,5");
}

void loop() {
  // rien, tout est fait au setup
}

// ---------- Fonctions utilitaires ----------

// angle 0–180° → pulse pour servos ANGLE [web:7][web:71]
uint16_t angleToPulse(int angle) {
  if (angle < 0) angle = 0;
  if (angle > 180) angle = 180;
  return map(angle, 0, 180, SERVOMIN_ANG, SERVOMAX_ANG);
}

// Met un servo POSITIONNEL à un angle donné
void setAngleServo(uint8_t ch, int angle) {
  uint16_t p = angleToPulse(angle);
  pwm.setPWM(ch, 0, p);
  Serial.print("Canal "); Serial.print(ch);
  Serial.print(" -> "); Serial.print(angle); Serial.println(" deg");
}

// Met un servo CONTINU à l'arrêt (neutre)
void setContinuousStop(uint8_t ch) {
  pwm.setPWM(ch, 0, PULSE_STOP);
  Serial.print("Canal "); Serial.print(ch);
  Serial.println(" (continu) -> STOP");
}
